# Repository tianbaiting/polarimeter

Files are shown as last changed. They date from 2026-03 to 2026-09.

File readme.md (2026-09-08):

# Deuteron Beam Polarimeter Engineering Repository

The current project baseline contains two compact in-vacuum polarimeters:

1. `CompactInVacuum-afterSRC`, downstream of SRC.
2. `CompactInVacuum-preSAMURAI`, before the SAMURAI terminal.

They share the detector head, three-channel sector-holder architecture, SiPM/scintillator
technology, passive in-vacuum services, calibration approach, and physics studies. Chamber
geometry, beam interfaces, target integration, supports, and maintenance envelopes remain
deployment-specific and must be verified independently.

The external-detector models are preserved under `external_version/` as legacy/reference routes.
Their H+V+V mechanics and historical interface assumptions are not requirements for either
current CompactInVacuum instrument.

## Current architecture

| Workstream | Status | Detector location | Mechanical authority |
|---|---|---|---|
| `compactOneAfterSRC` | current baseline prototype | in vacuum | `docs/specs/compact_one_requirement_baseline.md` |
| `compactOneInfrontSamurai` | current baseline prototype | in vacuum | `docs/specs/compact_one_requirement_baseline.md` |
| `compactInVacuum` | compatibility numerical/CAD scaffold | in vacuum | `docs/specs/compact_one_requirement_baseline.md` |
| `afterSRC` | legacy/reference | outside vacuum | `docs/specs/BLP_v1_requirement_baseline.md` |
| `infrontofSamuraiMag` | legacy/reference | outside vacuum | `docs/specs/BLP_v1_requirement_baseline.md` |

The current afterSRC screening profile uses a provisional 440 x 440 mm square chamber, a
420 mm body, and a top all-metal ICF305 maintenance opening. The removable blank flange owns no
detector support, locating datum, ground termination, or permanent cable restraint. ICF253 is the
rejected access comparison and ICF356 is the enlarged-envelope comparison. The first 12 mm holder
release is validated; the complete reorientation and lift through the port remains unresolved.
Beamline and service-interface values remain evidence-qualified and are not fabrication contracts.

## Repository map

- Start reading the documentation with [中文导航](docs/index_zh.tex) or
  [English guide](docs/index_en.tex). Run `make -C docs` to build the linked reading PDFs.
- `docs/physics/`: polarization production, density matrices and spin transport.
- `docs/analysis/`: counting statistics, coincidence and energy-loss studies.
- `docs/papers/`: research manuscript drafts.
- `compactInVacuum/`: current common platform, both baseline deployment profiles, compatibility
  scaffold, generator, validation, and tests.
- `external_version/afterSRC/`: preserved afterSRC external-detector reference.
- `external_version/infrontofSamuraiMag/`: preserved SAMURAI-front external-detector reference.
- `code/`: ROOT/C++ reconstruction, coincidence, polarization, and plotting tools.
- `docs/specs/compact_one_requirement_baseline.md`: current CompactInVacuum requirement authority.
- `docs/specs/BLP_v1_requirement_baseline.md`: legacy external-route requirement authority.
- `docs/polarimeter_detector/compact_in_vacuum_sipm_report/`: reproducible detector, vacuum,
  energy-loss, and procurement study.
- `docs/beamline_info/`: site-interface evidence and open questions.
- `codex_targets.yaml`: stateful module registry.
- `worklog.md`: cross-module execution and handoff history.

## CompactInVacuum platform

The common hierarchy is:

`active plastic -> optical package -> SiPM -> detector head -> three-channel sector holder -> four-sector internal assembly -> deployment chamber`

The recommended starting head uses a 20 mm diameter, 5.5 mm fast-blue plastic active element and
an NDL EQR15-class SiPM. These values remain prototype recommendations until supplier, optical,
vacuum, and bench-test gates close. Dedicated temperature and housekeeping hardware is not part of
schema 3.

Compatibility labels containing `CompactOne` remain in executable paths; the authoritative
instrument names are `CompactInVacuum-afterSRC` and `CompactInVacuum-preSAMURAI`.

See `compactInVacuum/README.md` for generation details.

## Stateful CAD workflow

The pipeline is:

`target.yaml -> resolved configuration -> generator -> validator -> FCStd/STEP/JSON -> state.json`

Current baseline entries:

```bash
./compactInVacuum/run_compactOne_afterSRC.sh --pipeline-index codex_targets.yaml
./compactInVacuum/run_compactOne_infrontSamurai.sh --pipeline-index codex_targets.yaml
```

Compatibility scaffold:

```bash
./compactInVacuum/run_compactInVacuum.sh --pipeline-index codex_targets.yaml
```

Preserved legacy references:

```bash
./external_version/afterSRC/run_afterSRC.sh --pipeline-index codex_targets.yaml
./external_version/infrontofSamuraiMag/run_infrontofSamuraiMag.sh --pipeline-index codex_targets.yaml
```

Targets and configuration are human-owned. Runtime state, locks, generated CAD, and validation
reports are machine-written. Interpret a result using both validation status and validation mode:
a non-strict pass is a prototype geometry pass, not a fabrication/release pass. Fabrication claims
require `strict=true`, `status=pass`, and closure of the applicable supplier, interface, access,
vacuum, site-envelope, and structural evidence gates.

## Cross-machine reproducibility

Compare Git commit, resolved configuration, FreeCAD/Python versions, validation mode/results,
solid counts and bounding boxes, volumes and screening masses, detector coordinates and physics
metrics, target states, service routing, and access checks. Byte-identical FCStd or STEP output is
not required.

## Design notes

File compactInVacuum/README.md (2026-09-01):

# CompactInVacuum Common Platform

The baseline comprises:

- `CompactInVacuum-afterSRC`
- `CompactInVacuum-preSAMURAI`

The `compactInVacuum/` and `CompactOne` names remain executable compatibility labels. External detector routes remain preserved legacy/reference implementations and are not modified by the common-platform redesign.

## Preferred hierarchy

`detector head -> three-channel sector holder -> four-sector internal assembly -> deployment chamber`

The old 35 mm nose, 44 mm cassette box, long cassette thermal bridge, independent wall rails, wall anchors, and temperature/housekeeping system are superseded.

## Detector head

The default prototype contains:

- 20.0 × 5.5 mm fast plastic active element;
- 0.25 mm reflector envelope;
- 0.50 mm optical coupling;
- 1.50 mm NDL EQR15-class SiPM package;
- 1.20 mm provisional sensor PCB/carrier;
- 1.00 mm rear mounting face;
- shallow light-tight sleeve;
- 3.0 mm short cable exit;
- separate 20.0 mm connector keepout.

Calculated physical housing depth:

`5.50 + 0.50 + 1.50 + 1.20 + 0.00 + 1.00 = 9.70 mm`

Cable and connector keepouts do not increase this metric. The default gate is 18.0 mm.

## Sector holder

One coherent carrier holds deuteron, small-angle proton, and large-angle proton heads. Each nest has an insertion stop, D-flat anti-rotation land, removable clamp bridge, and two provisional M3 fastener envelopes. One common plate provides acceptance relief, a rear cable lane, survey datums, and a plane–pin–slot chamber interface.

Heads remove rearward after clamp release. For the current afterSRC fixed-wall study, exact solid
poses validate only the first 12 mm inward release from the stationary support. The subsequent
translation, reorientation, and lift through the top ICF305 opening remain unresolved; the former
70 mm straight radial motion is not evidence of complete extraction.

The removable access closure owns no detector support, locating datum, protective-ground
termination, or permanent cable restraint. All holder load paths remain on stationary supports
that contact permanent chamber walls.

## Monitoring disposition

Dedicated temperature monitoring is removed. There is no physical sensor, temperature harness, required temperature channel, housekeeping capacity rule, or housekeeping feedthrough. Schema version 3 rejects the removed fields.

## Display roles

Physical and purchased-component/interface objects are visible by default. Keepouts, datums, service centerlines, physics acceptance, and optional reference objects are hidden. Active plastic, coupling, SiPM, carrier, housing, and holder have distinct inspection colors when GUI state is available.

## Configuration

- Common schema-v3 platform: `config/common_detector.yaml`
- afterSRC deployment: `config/afterSRC_compact.yaml`
- pre-SAMURAI deployment: `config/infrontSamurai_compact.yaml`
- legacy entry-point compatibility: `config/default_compactInVacuum.yaml`

See `MIGRATION.md` for rejected fields and mappings.

## Generation and validation

```bash
./compactInVacuum/run_freecad_tests.sh

./compactInVacuum/run_compactOne_prototypes.sh \
  ./compactInVacuum/config/afterSRC_compact.yaml \
  ./compactInVacuum/artifacts/prototypes

./compactInVacuum/run_compactOne_afterSRC.sh \
  --pipeline-index codex_targets.yaml \
  --force-rebuild

./compactInVacuum/run_compactOne_infrontSamurai.sh \
  --pipeline-index codex_targets.yaml \
  --force-rebuild
```

Non-strict validation permits documented evidence warnings but never geometry, collision, capacity,
or acceptance failures. A non-strict pass is a prototype geometry result, not a fabrication release.
Strict mode additionally requires supplier drawings, site envelopes, vacuum-material evidence,
chamber-access closure, and pressure-vessel analysis. It does not require removed monitoring hardware.

Generated CAD, screenshots, caches, and runtime state remain untracked unless intentionally selected as reference artifacts.

## Physics disposition

The redesign preserves 53.4° for the large-angle proton and 11.2° for the small-angle proton. Previously supplied nominal values of approximately 55.9° and 11.3° remain unresolved pending evidence.

## Authorities

- `docs/specs/compact_one_requirement_baseline.md`

Supporting records:

- `docs/specs/compact_one_architecture_audit.md`: dated implementation snapshot; later baseline
  revisions supersede conflicting extraction or access claims.
- `compactInVacuum/MIGRATION.md`: schema migration guide, not a mechanical requirement authority.

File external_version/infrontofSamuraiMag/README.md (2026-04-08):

# infrontofSamuraiMag User Guide

This module builds, validates, and exports the BLP v1 in-front polarimeter concept assembly.

## 0. Worklog Protocol (Mandatory)

Before edits/runs, read:
- `worklog.md`
- `infrontofSamuraiMag/worklog.md`

After every stateful run (including `--validate-only`), append one English entry to both files with:
- timestamp (UTC + local),
- command and key overrides,
- validation/state result,
- next action.

## 1. Run Commands

Stateful pipeline entry (required for module work):

```bash
./infrontofSamuraiMag/run_infrontofSamuraiMag.sh --pipeline-index codex_targets.yaml
```

Legacy ad-hoc entry scripts have been removed. Use the stateful shell entry above instead of direct one-off Python or FreeCAD macro wrappers.

Force rebuild (bypass hash-skip):

```bash
./infrontofSamuraiMag/run_infrontofSamuraiMag.sh --pipeline-index codex_targets.yaml --force-rebuild
```

Validate only (strict gate):

```bash
./infrontofSamuraiMag/run_infrontofSamuraiMag.sh --pipeline-index codex_targets.yaml --validate-only --strict-validation
```

V2 full-path LOS trial (legacy mode with overrides):

```bash
./infrontofSamuraiMag/run_infrontofSamuraiMag.sh --pipeline-index codex_targets.yaml --validate-only --strict-validation \
  --set geometry.clearance.los_scope=v2_fullpath \
  --set geometry.chamber.los_channels.enabled=true \
  --set geometry.chamber.los_channels.channel_diameter_mm=96.0 \
  --set geometry.chamber.los_channels.channel_start_z_mm=8.0 \
  --set geometry.chamber.los_channels.channel_length_mm=1600.0 \
  --report-json /tmp/infront_v2_los_report.json
```

## 2. CLI Options

- `--config <path>`: config file path.
- `--set <key=value>`: dotted override (repeatable).
- `--output-dir <path>`: override `output.dir`.
- `--basename <name>`: override `output.basename`.
- `--formats <csv>`: override output formats (`fcstd,step`).
- `--dump-resolved-config`: print normalized config snapshot.
- `--doc-name <name>`: FreeCAD document name.
- `--validate-only`: run validation without CAD export.
- `--strict-validation` / `--no-strict-validation`: exit non-zero on validation fail.
- `--report-json <path>`: explicit report path.
- `--angle-tol-deg <v>`: angle tolerance.
- `--radius-tol-mm <v>`: radius tolerance.
- `--pipeline-index <path>`: resolve target/state from root index.
- `--force-rebuild`: force run even if target hash unchanged.

## 3. Development Environment (Reproducible)

Create a dedicated virtual environment for tests and config checks:

```bash
python3 -m venv infrontofSamuraiMag/.venv-pytest
infrontofSamuraiMag/.venv-pytest/bin/pip install -r infrontofSamuraiMag/requirements-dev.txt
```

Run test gate:

```bash
infrontofSamuraiMag/.venv-pytest/bin/python -m pytest -q infrontofSamuraiMag/tests
```

Layered test gate with dependency precheck:

```bash
infrontofSamuraiMag/.venv-pytest/bin/python infrontofSamuraiMag/scripts/precheck_test_env.py --layer pure_python
infrontofSamuraiMag/.venv-pytest/bin/python infrontofSamuraiMag/scripts/precheck_test_env.py --layer freecad_runtime
PYTHON_BIN=infrontofSamuraiMag/.venv-pytest/bin/python ./infrontofSamuraiMag/run_tests_layered.sh pure_python
PYTHON_BIN=infrontofSamuraiMag/.venv-pytest/bin/python ./infrontofSamuraiMag/run_tests_layered.sh freecad_runtime
```

## 4. Config Structure (`config/default_infront.yaml`)

### 4.1 geometry.beamline
- `axis`
- `inlet_diameter_mm`

### 4.2 geometry.chamber
- `core.size_x_mm / size_y_mm / size_z_mm / wall_thickness_mm`
- `end_modules.front_standard / rear_standard`
- `end_modules.module_outer_diameter_mm / module_inner_diameter_mm / module_thickness_mm`
- `end_modules.seal_face_width_mm / bolt_circle_diameter_mm / bolt_count`
- `end_modules.oring_groove_width_mm / oring_groove_depth_mm`
- `end_modules.interface_bolt_* / interface_nut_* / interface_washer_*` (replaceable interface fastening hardware)
- `los_channels.enabled / channel_diameter_mm / channel_start_z_mm / channel_length_mm` (used by LOS v2 full-path channel cuts)

### 4.3 geometry.ports
- `main_pump / gauge_safety / rotary_feedthrough / spare`
- each port: `side / center_z_mm / inner_diameter_mm / outer_diameter_mm / length_mm`

### 4.4 geometry.plate.h / v1 / v2
- `orientation` (`horizontal` or `vertical`)
- `mount_plane` (`xy` for H, `yz` for V1/V2; parser also accepts `xz` for non-default layouts)
- `offset_mode` (`manual` or `auto`; auto resolves plate-normal offset to minimum outside-chamber position + `plate_auto_gap_mm`)
- pose: `z_mm / offset_x_mm / offset_y_mm`
- panel: `width_mm / height_mm / thickness_mm`
- LOS opening: `inner_radius_mm / outer_radius_mm / sector_opening_deg / azimuth_centers_deg[]`
- load-bearing: `lug_* / bolt_hole_* / stiffener_*`

### 4.5 geometry.detector
- `clamp`: detector body/clamp/support parameters
  - includes `support_mount_block_*` and `support_mount_hole_diameter_mm`
  - includes `clamp_ear_* / clamp_bolt_* / anti_rotation_key_*` for split-clamp fastening and anti-rotation key features
- `adapter_block`: fixed-angle transition block parameters

### 4.6 geometry.target
- `ladder`: 3-position ladder + drive semantics
  - includes `motor_mount_* / hard_stop_* / index_*`
- `holder`: removable holder and target thicknesses
  - includes `clamp_screw_*` for dual-screw clamp realization

### 4.7 geometry.stand
- base/support/anchor/leveling/shim parameters
- includes `plate_tie_*` for plate-to-stand load-transfer columns/caps/bolts

### 4.8 geometry.clearance
- `los_scope` (`v1_conceptual` or `v2_fullpath`)
- `los_margin_mm`
- `vv_min_gap_factor` (V1/V2 clear-gap multiplier against detector clamp outer diameter; default `2.0`)
- `plate_auto_gap_mm` (minimum plate-normal gap used by auto offset solver)
- `plate_chamber_cutout_margin_mm` (plate-vs-chamber cutout margin; default `5.0`)
- `los_detector_active_face_offset_mm`
- `detector_front_to_chamber_mm`
- `detector_pair_min_gap_mm`
- service clearances

### 4.9 layout
- `sectors: [left, right, up, down]`
- `channels[]`: `name / angle_deg / radius_mm / confidence`

### 4.10 output
- `dir / basename / formats`

## 5. Validation Report

JSON report is grouped by subsystem:
- `chamber`
- `plates`
- `detector`
- `target`
- `stand`

Global pass condition requires all subsystem checks to pass.

## 6. Artifacts

Expected outputs:
- `*.FCStd`
- `*.step`
- `*.validation_report.json`
- `state.json` (stateful run record)

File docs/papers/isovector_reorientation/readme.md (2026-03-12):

Section IV.  {Simulation of the detection at SAMURAI}

{ -subsection A: {detector setup}

  -subsection B: {target position optimization}
  
  -subsection C: {response of neutron with nebula}
  
  -subsection D: {response of proton with PDC}
  
  -subsection E: {Beam dumper and the background simulation}
  
  -subsection F: {Observation of the IVR effect in the current experimental design}
  
} 

We intend to optimize the reaction vertex in the SAMURAI dipole to make the best use of the coverage of the detectors. \textcolor{blue}{Here, $b$ is the impact parameter, defined as the perpendicular distance between the centers of the deuteron and target nucleus at closest approach, and $\rho$ is the nuclear matter density.} According to the Improved Quantum Molecular Dynamics (ImQMD) model calculations, for the scattering events with $b = 7 \sim 9$~fm, which is the range showing the most sensitivity of the IVR effect to the $\gamma$ parameter \textcolor{blue}{(where $\gamma$ characterizes the density dependence of the symmetry energy $E_{\rm sym}(\rho)$)}, the most probable direction of the breakup neutrons is not very close to $\theta = 0^\circ$. \textcolor{blue}{The SAMURAI spectrometer is a large-acceptance superconducting dipole magnet, providing high-resolution momentum analysis and wide angular coverage for charged particles.} Considering that NEBULA is difficult to move, in order to measure the neutrons in the most favorable range of $\theta_{\mathrm{n}}$, it is suggested to place the target upstream of the magnet, at a distance of 3 meters from the center of the magnet, which ensures that the range of $-10^\circ \leq \theta_{\mathrm{n}} \leq 10^\circ$ is covered for the most probable neutron emissions.

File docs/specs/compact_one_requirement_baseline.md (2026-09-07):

# CompactInVacuum Requirement Baseline v2.8

## 1. Authority and scope

This document is the requirement authority for the common CompactInVacuum detector platform and its two baseline deployments:

1. `CompactInVacuum-afterSRC`, downstream of SRC.
2. `CompactInVacuum-preSAMURAI`, upstream of the SAMURAI terminal.

Both deployments place the compact plastic-scintillator detector heads, SiPM packages, passive internal services, and sector holders inside vacuum. Detector technology and common mechanical architecture are shared. Chamber geometry, purchased beamline interfaces, target integration, external supports, and installation envelopes remain deployment-specific.

The external-detector implementations in `external_version/afterSRC/` and
`external_version/infrontofSamuraiMag/` are legacy/reference routes. They shall remain independently
testable and shall not be modified, deleted, or silently promoted into this baseline.

Compatibility labels containing `CompactOne` and the directory `compactInVacuum/` may remain in executable paths. The instrument names above are authoritative.

## 2. Decision and evidence states

Engineering selections use:

- `FROZEN`: approved project requirement.
- `PROVISIONAL`: current integration value requiring evidence.
- `RECOMMENDED`: preferred prototype candidate; alternatives remain open.
- `PLACEHOLDER`: architecture-only value that fails an applicable strict gate.
- `PURCHASED-PART-CONTRACT`: governed by a supplier or certified drawing.

Unknown quantities remain `TBD` or unresolved. Exact-looking dimensions shall not be invented.

Deployment interface claims use:

- `A — EXTERNAL CONSTRAINT`
- `B — LEGACY INHERITANCE`
- `C — ENGINEERING ASSUMPTION`
- `D — UNRESOLVED / TBD`

## 3. Frozen common-platform requirements

- Four sectors: LEFT, RIGHT, UP, DOWN.
- Three channels per sector: deuteron, small-angle proton, large-angle proton.
- Twelve active detectors total.
- Detector axes point toward the target center.
- Configured radii refer to active-plastic centers.
- One nominal 50-ohm signal path per detector; bias may share the coax through external bias tees.
- Active amplifiers, bias tees, and digitizers remain outside vacuum by default.
- One removable three-detector holder per sector.
- Full target-region-to-complete-active-disc acceptance is preserved.
- Coincidence geometry and per-channel active-acceptance metrics are exported.
- Physical CAD is separated from keepouts, datums, service centerlines, and physics overlays.
- Both baseline deployments generate independently.
- Preserved external routes remain unchanged and independently regressible.

## 4. Temperature-monitoring disposition

A dedicated temperature-monitoring or thermometer-style subsystem is not a platform requirement.

The common platform shall not contain or require:

- a physical `TemperatureSensor`;
- per-detector temperature channels;
- temperature harnesses or centerlines;
- wires-per-temperature-channel capacity;
- a housekeeping feedthrough;
- a housekeeping capacity gate;
- a resolved temperature-sensor supplier model;
- temperature manifests or generated metrics.

These elements shall be removed rather than hidden. Schema version 3 rejects their former configuration keys with a migration error.

An optional deployment-level spare auxiliary interface may be introduced in a future revision only if justified. It shall default to disabled, create no physical feedthrough or cable when disabled, use neither “temperature” nor “housekeeping” terminology, and remain outside required validation.

## 5. Detector-head prototype

The semantic axial stack is:

1. fast plastic scintillator;
2. thin reflector/light-treatment envelope;
3. optical coupling layer;
4. SiPM package;
5. minimal sensor PCB or metallic carrier;
6. shallow light-tight rear mounting face;
7. short cable exit.

The recommended starting prototype is:

| Component | Default value | Status |
|---|---:|---|
| active plastic diameter | 20.0 mm | recommended |
| active plastic thickness | 5.5 mm | recommended within 5–6 mm |
| reflector radial envelope | 0.25 mm | placeholder material |
| optical coupling thickness | 0.50 mm | provisional |
| SiPM package depth | 1.50 mm | recommended candidate envelope |
| sensor PCB/carrier depth | 1.20 mm | provisional |
| rear internal clearance | 0.00 mm | provisional |
| rear mounting-face thickness | 1.00 mm | provisional |
| SiPM candidate | NDL EQR15 11-6060D-S | recommended |
| SiPM active class | approximately 6 × 6 mm | recommended |

The default physical housing depth is calculated, not independently specified:

`5.50 + 0.50 + 1.50 + 1.20 + 0.00 + 1.00 = 9.70 mm`

The physical-depth gate is 18.0 mm maximum from active entrance face to rear physical housing. The 3.0 mm short cable exit and the 20.0 mm connector keepout are reported separately and do not increase this metric.

The reflector envelope surrounds the active plastic without covering its complete entrance face. The coupling contacts the active rear readout region. The SiPM is centered directly behind the coupling. The carrier contacts the SiPM and rear mounting face, providing a real passive conductive path without an artificial long thermal bridge.

The light-tight housing is a shallow sleeve and rear face. It shall not recreate the former 35 mm nose plus 44 mm rectangular package. Semiconductor microstructure and detailed connector internals are out of scope.

The rear mounting face provides the insertion stop and mounting datum. A D-flat and matching nest land provide anti-rotation without protruding into a neighboring acceptance cone. Detector removal is axial and rearward after clamp release. The default sampled withdrawal distance is 12.0 mm, sufficient to clear the 3.0 mm nest.

The carrier, cable exit, connector, reflector selection, and detailed PCB remain provisional until drawings or prototype measurements resolve them.

## 6. Sector holder

Each sector uses one coherent fabricated or machined carrier containing exactly:

- one deuteron detector head;
- one small-angle proton detector head;
- one large-angle proton detector head.

The active deployments use four detailed boxed carriers with two relieved cheeks, front/rear crossmembers, three rear nests and removable clamps, three routed passive coax connections, and one radial plane–pin–slot dock per sector. A common annular support near z=140 mm transfers load to the permanent side and bottom walls. The former rear C-frame is retained only as a comparison configuration.

A removable downstream retaining bridge clamps each dock with two axial screw envelopes. The bridge, screws, locating pins and coax/ground interfaces are represented for every sector. A rear-facing cylindrical handling journal projects behind each carrier; its capture tool remains vertical in the chamber coordinate system.

The specified service sequence is UP, RIGHT, LEFT, DOWN; installation reverses this sequence. It supersedes the former independent-removal design target for this prototype. Each module disengages radially inward, translates downstream, turns about its handling journal if needed, centers under the ICF305 port, and lifts upward. Other sectors remain physical obstacles until their preceding removal step is complete. Validation must distinguish loaded-module/capture-tool transport from connection release, retaining-bridge access, and purchased capture mechanism qualification. A clear transport path alone shall not be called a complete maintenance-process certificate.

The cheeks, crossmembers, nests, clamps, and fastener envelopes shall clear every complete active-acceptance cone. The crossmembers include the declared cable and handling-journal reliefs. Arbitrary per-detector wall rails, wall anchors, cylindrical thermal straps, and a synthesized wall backbone are prohibited.

The holder is a provisional manufacturable concept, not a released drawing. Tool access, chamber closure, pin retention, tolerances, surface finish, and production fasteners remain to be resolved.

Every removable sector-holder structural interface shall contact either a permanent chamber wall or a separately defined stationary load-bearing pad/pedestal with zero geometric gap. Every stationary pad/pedestal shall in turn contact a permanent chamber wall, or the explicitly defined common stationary support frame, with zero gap. The common frame shall contact permanent side/bottom walls with zero gap. A protective-ground strap is electrical bonding only and shall never be used to bridge a structural mounting gap or satisfy the load path.

## 7. Physical and overlay roles

Every generated object has one engineering role:

- `physical`
- `purchased_component_interface`
- `keepout`
- `datum`
- `service_centerline`
- `physics_acceptance`
- `optional_reference_geometry`

Default visibility is:

| Role | Default |
|---|---|
| physical | visible |
| purchased component/interface | visible |
| keepout | hidden |
| datum | hidden |
| service centerline | hidden |
| physics acceptance | hidden |
| optional reference geometry | hidden |

Generated documents use meaningful groups including `DetectorHead`, `SectorHolder`, `Target`, `Services`, `Chamber`, `Keepouts`, `Datums`, `PhysicsAcceptance`, and `OptionalReference` where applicable.

Material-based colors and transparency support inspection but are not geometry requirements. The active plastic, optical coupling, SiPM, PCB/carrier, housing, and holder shall remain visually distinguishable.

## 8. Services and passive thermal path

- Twelve signal channels are required.
- Four sector-grouped signal feedthrough interfaces provide sixteen provisional slots.
- One protective/equipotential bond per sector is required.
- Signal shields are not the sole protective-earth path.
- Each protective bond shall have nonzero physical length and contact both the removable holder/block and the stationary support/permanent chamber. A zero-length marker, virtual datum, locating pin, or coax shield does not satisfy this requirement.
- Cable routes, connector keepouts, bend envelopes, and centerlines are nonphysical overlays unless explicitly classified otherwise.
- No dedicated temperature or housekeeping feedthrough is generated.

The conductive path contract is:

`SiPM package -> sensor PCB/carrier -> rear mounting face -> detector nest -> sector carrier plate -> chamber mounting interface`

The path represents contact connectivity. It is not thermal FEA and shall not be satisfied by adding a fictitious long bridge.

## 9. Physics geometry

The repository values remain:

| Channel | Repository value | Previously supplied nominal | Disposition |
|---|---:|---:|---|
| proton large | 53.4° | approximately 55.9° | unresolved; do not change without evidence |
| proton small | 11.2° | approximately 11.3° | unresolved; do not change without evidence |

This mechanical redesign does not resolve the discrepancy. Active-center radii and directions remain unchanged.

Validation exports active-center angle/radius, active-face radius, angular extent, approximate solid angle, and eight configured coincidence pair metrics. It does not claim detector-response or Geant4 fidelity.

## 10. Acceptance and collision validation

The complete ruled volume from the active target region to each complete active disc is checked against:

- target hardware;
- every other detector head;
- carrier plates, nests, clamps, and interface blocks;
- simplified purchased fastener envelopes;
- cable and connector keepouts;
- service hardware;
- chamber hardware.

Validation also requires:

- twelve non-null, valid detector-head solids;
- no detector-head overlap;
- four non-overlapping three-head sector assemblies;
- clear detector withdrawal after clamp release;
- clear sampled configured holder-release poses, without treating them as proof of complete extraction;
- clear target motion sweep;
- clear signal routing;
- a closed vacuum control volume;
- all internal physical parts inside the selected chamber;
- connected passive thermal paths.
- zero-gap removable-holder-to-stationary-support and stationary-support-to-permanent-wall structural paths;
- no detector support, locating pin, ground bond, or permanent support inside the removable access-closure lift corridor.

## 11. Deployment profiles

### 11.1 CompactInVacuum-afterSRC

- Baseline instrument downstream of SRC.
- Selected screening chamber: square 440 × 440 mm internal section, provisional. The active ICF305 maintenance-access integration study length is 420 mm with the upstream outer face retained at `z=-50 mm`; the former 360 mm body remains the ICF253 comparison envelope and is not silently treated as the active access-port design.
- A cylindrical afterSRC chamber is not part of the selected CompactInVacuum-afterSRC profile.
- Front/rear ICF114 values are legacy/provisional evidence, not approved site requirements.
- The maintenance opening is a top-wall circular ICF port with a removable ICF blank flange. Elastomer/O-ring sealing is prohibited for this deployment; the screening seal is an oxygen-free-copper metal gasket. The maximum allowable helium leak rate is `1.0e-10 Pa m^3/s`, based on the user-supplied Toshiba inspection sheet; document identity and applicability to the complete compact chamber remain to be closed before fabrication release.
- The access-port comparison family is `ICF253`, `ICF305`, and `ICF356`. Vendor-catalog screening dimensions distinguish the flange hole from the applicable pipe outside diameter: ICF253 uses a `198.5 mm` flange bore / `203 mm` pipe OD, ICF305 uses `251.0 mm` / `254 mm`, and ICF356 uses `301.8 mm` / `305 mm`. ICF305 is the active recommended prototype; ICF253 remains a smaller-port comparison requiring reorientation; its former side-wall UP-holder rejection is historical and shall not be applied unchanged to the new common-frame carrier, and ICF356 remains the enlarged-envelope comparison.
- A top access flange alone does not close the sector-removal requirement. Validation shall separately report: flange-to-chamber fit, flange-to-service-port clearance, detached-holder passage screening, and the complete installed-holder release/reorientation/lift path. The existing straight `70 mm` radial release path shall not be re-labelled as a successful top-port extraction path.
- The removable ICF fixed/blank closure owns no detector support, locating datum, structural fastener, thermal sink, protective-ground termination, cable clamp, or target-mechanism load. Removing the blank flange shall leave all internal detector supports positioned on permanent chamber structure.
- Both compact deployments use the boxed carriers and annular support defined above, four radial sector docks, and deployment-specific permanent-wall feet. This supersedes the former afterSRC UP `-X` pedestal at `y=180 mm`.
- Available envelope, the complete service-removal motion, purchased ICF305 interface drawing, support datum, and pressure-vessel release remain unresolved.
- The preserved external afterSRC route remains a legacy fallback/reference.

### 11.2 CompactInVacuum-preSAMURAI

- Baseline instrument upstream of the SAMURAI terminal.
- Selected screening chamber: square 450 × 450 mm internal section, provisional; the ICF305 top-access prototype uses a 420 mm body with upstream outer face at `z=-50 mm`. The former 380 mm service-plate chamber remains a comparison candidate.
- The top maintenance opening adopts the same provisional ICF305 geometry and load-free closure as afterSRC; supplier, seal/site applicability, and complete extraction evidence remain unresolved. Signal services occupy the permanent upstream top strip outside the maintenance flange.
- VF100/VG80 evidence inherited from external work is not automatically authoritative for the compact deployment.
- Available envelope, mating-chain ownership, service-removal closure, purchased interface drawings, support datum, and pressure-vessel release remain unresolved.
- The preserved external SAMURAI-front route remains reference engineering work.

## 12. Strict-validation semantics

Non-strict mode permits explicit warnings for unresolved supplier, material, site-envelope, chamber-access, and pressure-vessel evidence. Geometry, capacity, acceptance, collision, and schema failures remain fatal.

Strict mode converts applicable evidence warnings to failures. Strict validation shall not fail because a removed temperature sensor, temperature harness, housekeeping channel, or housekeeping feedthrough is absent.

Current legitimate strict gates include:

- reflector/optical and SiPM supplier evidence;
- carrier/PCB definition;
- purchased beam and signal-interface drawings;
- vacuum material and cleaning evidence;
- chamber external-pressure/buckling FEA;
- site envelopes;
- resolved sector-removal access closure.
- afterSRC maintenance-port metal-seal evidence, helium-leak acceptance, flange/service clearances, and complete extraction motion.

## 13. Schema migration

CompactInVacuum schema version 3 replaces:

- `detector.cassette` with `detector.head`;
- `sector_cartridge` with `sector_holder`;
- arbitrary outer detector length with calculated stack depth;
- protruding `anti_rotation_tab_mm` with `anti_rotation_flat_depth_mm`.

Schema version 3 rejects all former temperature and housekeeping fields. They are not ignored and no compatibility geometry is created. Deployment service-port roles are limited to `rotary` and `signal`.

Legacy schema-1 compatibility profiles remain loadable for the preserved old entry point, but their dedicated housekeeping block has also been removed.

## 14. Required artifacts

The redesign shall generate:

- isolated detector head: FCStd, STEP, geometry metrics JSON, PNG;
- transparent/exploded detector head: FCStd, STEP, geometry metrics JSON, PNG;
- three-channel sector holder: FCStd, STEP, geometry metrics JSON, PNG;
- four-sector internal assembly: FCStd, STEP, geometry metrics JSON, validation JSON, PNG;
- CompactInVacuum-afterSRC: FCStd, STEP, geometry metrics JSON, validation JSON, PNG;
- CompactInVacuum-preSAMURAI: FCStd, STEP, geometry metrics JSON, validation JSON, PNG;
- before/after comparisons for detector side, sector, and internal assembly;
- separate diagnostic renders with keepouts and acceptance volumes visible.

Runtime state, caches, and machine-specific files remain untracked.

## 15. Evidence still required

- Approved afterSRC and pre-SAMURAI site envelopes and interface drawings.
- Certified purchased beam-interface and signal-feedthrough drawings.
- Resolved PCB/carrier, connector, cable, strain-relief, reflector, and optical-pad choices.
- Prototype optical collection, timing, uniformity, saturation, and vacuum/bake testing.
- Sector-holder tolerances, tool access, pin retention, fasteners, finish, and fabrication drawings.
- Chamber access closure and sector extraction demonstration.
- Vacuum material/cleaning qualification.
- Chamber external-pressure, weld, support, transport, and seismic/load analysis as applicable.
- Evidence resolving 53.4° versus approximately 55.9°, and 11.2° versus approximately 11.3°.

## 16. Change history

- 2026-09-07 v2.8: user selected top rotary, left-wall signal feedthroughs and right-wall maintenance access; replace the inaccessible annular weldment with individually installable local supports and include initial support installation in validation.

- 2026-09-07 v2.7: promoted four detailed boxed modules to both canonical deployments, with a permanent annulus, downstream retaining bridges, rear handling journals, complete installed/parked signal looms and the UP/RIGHT/LEFT/DOWN service sequence. Loaded-module and modeled capture/bridge motion remain distinct from full service-tool and fabrication qualification.

- 2026-09-06 v2.6: authorized one detailed RIGHT-sector boxed-carrier study on a near-detector annular support, with connector disconnection, tool access and complete controlled extraction. This is an isolated design study, not replacement of either canonical deployment.
- 2026-09-06 v2.5: selected the common rear open C-frame, four axial-release sector docks, and top ICF305 access for both compact prototypes; retained independent complete extraction as an unresolved design target.

- 2026-09-01 v2.4: clarified that sampled holder-release poses do not constitute proof of the
  complete extraction path; aligned downstream documentation and validation terminology with the
  ICF305 fixed-wall support design.
- 2026-07-27 v1.0: established a common CompactInVacuum platform with two baseline deployments.
- 2026-07-29 v2.0: removed temperature monitoring end-to-end; replaced the long cassette with a 9.70 mm calculated detector head; replaced arbitrary rails with one coherent sector carrier; added engineering display roles, removal validation, and schema-v3 migration.
- 2026-07-29 v2.1: selected the square 440 × 440 mm screening chamber for CompactInVacuum-afterSRC and removed its cylindrical chamber candidate.
- 2026-08-30 v2.2: froze the afterSRC maintenance opening as an all-metal top ICF port with an oxygen-free-copper gasket and `1.0e-10 Pa m^3/s` helium-leak criterion; added ICF253/305/356 comparison candidates, selected ICF305 for the active prototype, and kept complete sector extraction as an independently validated unresolved motion.
- 2026-08-30 v2.3: prohibited all detector support/datum/ground ownership on the removable ICF closure; required zero-gap removable-holder-to-stationary-pad-to-permanent-wall load paths; and moved the afterSRC UP-sector mount from the opened `+Y` wall to a stationary `-X` side-wall pedestal while keeping the long wall-reaching member out of the removable holder.

## 17. Boxed-sector design study

The registered `compactBoxedSectorStudy` first develops one complete RIGHT sector using the unchanged three active detector positions and the afterSRC ICF305 chamber. Its candidate carrier uses two side cheeks, three nests, local crossmembers, a plane-pin-slot docking foot and an accessible draw screw. A fixed annular support near the large-angle detector transfers load to permanent side/bottom walls. The ring is retained during routine detector maintenance; segmentation and fabrication release are separate decisions.

The study must include real detector-head solids, retention and docking interfaces, three passive pigtails and their disconnect envelopes, protective bonding, a defined grasping joint and the handling-tool envelope. The other three sectors are reserved by conservative module envelopes, supplemented by their actual detector-head solids. Results shall explicitly identify this single-sector scope.

Maintenance is performed with the blank flange and gasket removed. Connector plugs are withdrawn and parked before the module moves. A capture tool supports the module before its draw screw is removed. The module releases inward, translates downstream, turns on a controlled joint whose axis is parallel to beam Z, centers below the opening and lifts out. The handling rod stays vertical. This refines the conceptual beam-axis turn into an executable tool-controlled motion.

Check the complete modeled motion against permanent support, chamber, flange, services and the three reserved sectors. Discrete clear poses alone do not prove motion clearance: use analytic swept envelopes or interval certificates based on minimum shape distance and an upper bound on point displacement. Any collision or interval left uncertified shall fail the motion gate. Intended mating contacts require explicit geometric certificates; they cannot be bypassed by blanket obstacle exclusions. The full aperture is retained; do not shrink an arbitrary keepout to make a mechanism pass.

Transport dimensions, microcoax bend radius, connector/capture-tool envelopes and fabrication details are provisional. Geometry certification applies only to those modeled envelopes. Supplier/material qualification, stiffness, clamp preload, human reach/handling forces and available external headroom remain strict evidence gates. No manufacturing release or four-sector detailed-assembly claim follows from this study.

## 18. Complete boxed deployment integration

Both canonical deployments shall export all four detailed carriers, twelve complete detector heads, four locating-pin pairs and retaining bridges, twelve installed signal looms, four ground bonds, the common permanent annular support, the selected chamber, target and deployment-specific beamline interfaces. Neighbor reservation boxes are not a substitute for any of the four physical modules.

The common dimensional source is `compactInVacuum/config/common_boxed.yaml`. Sector placement, removal order, rear handling journal, axial retaining bridges and service-parking coordinates are provisional integration parameters there. The upper-sector parking fixture attaches to the permanent left wall, clear of the top opening. The rear journal and tool provide a path behind the three loaded detector heads, especially for the final DOWN removal. A separate maintenance-open document and extraction poses supplement each closed canonical assembly. The original single-RIGHT-sector study remains a reproducible comparison and does not certify the complete deployments.

All strict evidence gates in section 12 apply to the new canonical engine, including beam/signal/access supplier drawings, materials and optical components, chamber pressure integrity, site/overhead envelope, fastener and capture-mechanism detail, and physical service handling. Geometry failures remain fatal; unresolved evidence remains explicitly non-strict prototype-only.

The full-deployment inward staging travel is 40 mm before the 96 mm downstream transfer. This reduces the rear handling-rod offset to 30 mm, keeping the complete vertical rod inside the circular opening during transfer. It replaces the single-sector study's 14 mm initial release for the full deployment; detector operating positions remain unchanged.

Each retaining bridge first disengages downstream by 20 mm, steps radially outward by 20 mm to clear the rear crossmember, steps 26 mm tangentially away from the engaged handling rod, transfers another 40 mm downstream, centers below the opening and lifts out. The loose bridge and fastener solids are included in the trajectory checks; the actuating/holding tool remains a purchased-mechanism qualification item.

## 19. Side-access baseline superseding the annular support

The two active deployments retain the rotary target axis and its feedthrough on the positive-Y top wall. The four signal feedthroughs move to the negative-X side wall. The metal-sealed ICF305 maintenance opening moves to the positive-X side wall; its center starts at y=0, z=190 mm. Beam interfaces remain on the upstream/downstream Z end walls and retain their deployment-specific contracts. All twelve active detector coordinates remain frozen. Sections 6, 11 and 18 describe the preceding annular prototype wherever inconsistent with this section; it is preserved as a reference only.

There shall be no annular support in the new physical assembly. UP, DOWN and LEFT use short local wall supports. RIGHT uses a local cantilever rooted on permanent wall upstream of the maintenance opening. Small factory-welded wall pads, blind mounting bores, removable support bodies, mounting fastener envelopes and locating pins are modeled. The removable closure and its flange shall carry no detector support or permanent cable load. Every removable support body shall have a checked insertion path through the side opening into the otherwise empty chamber; endpoint fit or contact area alone is insufficient. Factory welding, final machining, chamber deformation and bolt preload remain fabrication evidence gates.

The provisional removal sequence is RIGHT, DOWN, UP, LEFT, reversed for installation. Inward staging starts at 42 mm, downstream transfer at 96 mm, and extraction is toward +X. Capture geometry retains gravity-supporting journal contact while the operating rod approaches horizontally. Capture approach, module motion, retaining-bridge motion and initial support installation shall be reported separately from unqualified flexible service handling and purchased tool internals. The conservative contact and continuous-motion requirements in section 17 remain applicable.

Side-port configuration lives in the two selected deployment YAML files; common support and handling parameters live in `config/common_side_access.yaml`. Both canonical closed/open FCStd assemblies, four real loaded sectors and each sector's side-extraction keyposes are required. A successful ring-era report shall not be reused as side-access evidence.

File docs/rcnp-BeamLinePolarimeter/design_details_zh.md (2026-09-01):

# RCNP BLP 设计细节查询

> 状态：2026-09-01 重新分类为外置探测器/RCNP 类比参考。本文中的 50 mm 外置探测器、
> 0.40/0.62 m 半径、窗口薄膜和多靶位线性靶梯不是当前 CompactInVacuum 基线约束。
> 当前需求以 `docs/specs/compact_one_requirement_baseline.md` 为准；外置参考模型位于
> `external_version/infrontofSamuraiMag/`。

## 1. 文档目标与范围

本文整理 RCNP（大阪大学核物理研究中心）WS 束流线 BLP（Beam Line Polarimeter）相关公开资料中的机械与工艺要点，面向本项目 FreeCAD 建模使用。重点关注：

- BLP 在 WS 束流线中的位置与功能
- 散射室开孔、窗口、密封与真空接口
- 靶梯（target ladder）与线性馈入机构
- 探测器几何与支撑思路
- 与本仓库 legacy external `infrontofSamuraiMag` 参考参数的历史映射

本文不替代 RCNP 内部工程图纸；公开资料缺失的尺寸会明确标注为“待定参数”。

## 2. 已确认的核心几何与实验事实

### 2.1 BLP 几何与测量模式

- WS 束流线上使用 BLP1/BLP2 监测束流状态与极化，BLP 在设施布局图中有明确标注 [2][3][4]。
- BLP 水平面几何采用散射-反冲符合计数，典型角度为：
  - 散射角约 `17.0°`
  - 反冲角约 `69.7°` 或 `70.5°`（不同文献/版本略有差异）[2][3][4][5]。
- BLP 使用塑料闪烁体对（L/R/U/D）进行符合测量 [2][3][5]。

### 2.2 分析靶信息（公开文献）

- 曾使用 `CH2` 与 aramid（芳纶）作为分析靶 [2][3][4]。
- 文献中可见如下量级：
  - CH2 面密度：约 `8.4 mg/cm²`
  - aramid 面密度：约 `5.0 mg/cm²`
  - 另有薄膜厚度级别 `4 μm` 的 aramid 描述 [2][3]。

### 2.3 相关窗口与薄膜参数（公开文献）

注意：以下窗口参数中，部分来自 GR/VDC/气体靶系统，不全是“BLP 本体出射窗”直接尺寸，但对材料和薄膜工艺有直接参考价值。

- `Entrance/exit window`: `12.5 μm` aramid 或 carbon-aramid 薄膜 [3][5]。
- VDC cathode：`10 μm` carbon-aramid 薄膜 [3][5]。
- 气体靶 cell 示例：aramid 窗厚 `6 μm`，窗口尺寸约 `58W × 28H mm²` [2]。

## 3. 散射室机械设计要点（可直接映射到 CAD）

### 3.1 室体与主束流通道

- 室体形态：公开资料中可见“箱式/紧凑散射室”工程图与照片 [6]。
- 主束流轴应保留入口/出口通道，且出口可适度放大以降低边缘打束风险（工程上常用的背景抑制策略）。
- 材料优先非磁/弱磁不锈钢（如 304/316L）。

建议建模字段（参数化）：

| 参数 | 建议类型 | 当前值状态 |
|---|---|---|
| chamber 外形尺寸 | mm | 待定（由现场安装空间反推） |
| 壁厚 | mm | 待定 |
| 束流入口孔径 | mm | 参考级别：80–100（需现场确认） |
| 束流出口孔径 | mm | 建议不小于入口 |
| 入口/出口法兰标准 | 枚举 | 待定（CF/ISO 需选型） |

### 3.2 散射粒子窗口

- 窗口开孔应按运动学方向布置（至少覆盖 L/R 对；若包含 U/D 则补充垂直平面窗口）。
- 窗口结构建议采用：
  - 室壁开孔
  - 压环（retaining ring）
  - 薄膜（Kapton/aramid 方案二选一，按真空与散射损失折中）
- 薄膜厚度选型建议在文献可见范围内选点，并通过强度校核后定版。

建议建模字段：

| 参数 | 建议类型 | 当前值状态 |
|---|---|---|
| 窗口中心角度（水平） | deg | 可用：17.0, 69.7/70.5 相关几何派生 |
| 窗口开孔直径/扇角 | mm/deg | 待定 |
| 薄膜材料 | 枚举 | Kapton / aramid（待定） |
| 薄膜厚度 | μm | 参考级别：6, 10, 12.5 |
| 压环外径与厚度 | mm | 待定 |

### 3.3 真空接口

应预留：

- 泵口（涡轮分子泵）
- 真空计口
- 安全泄压/检修口

这些接口在 CAD 中应作为独立零件或标准件占位体，便于后续替换为具体法兰标准。

## 4. 靶梯（Target Ladder）与馈入机构

公开资料支持“多靶位 + 线性馈入”的结构思路 [2][6]。可按五槽位方案建模：

| 槽位 | 功能 | 典型内容 |
|---|---|---|
| 1 | 分析靶 | CH2 / aramid |
| 2 | 标定靶 | C 靶 |
| 3 | 观察屏 | 荧光屏 |
| 4 | 空框 | empty frame |
| 5 | 直通 | no target |

机构要点：

- 垂直导向（双导轨）
- 顶部线性馈入杆
- 波纹管真空隔离段
- 目标定位重复精度指标（工程目标）建议优于 `0.1 mm`（最终需实验团队确认）

## 5. 探测器与支撑结构

### 5.1 legacy external 历史约束（非当前 compact 基线）

保留的旧外置路线曾采用“探测器外壳为直径 `50 mm` 圆柱，前表面中心位于给定角度与半径”的包络：

| 粒子通道 | 角度（lab） | 半径 |
|---|---:|---:|
| deuteron | 20.9° | 0.40 m |
| proton-1 | 11.2° | 0.62 m |
| proton-2 | 53.4° | 0.62 m |

这三组是 legacy external 布置的历史参考，既不是 RCNP 原始 BLP 的一一复刻参数，
也不是当前 CompactInVacuum 配置。当前 compact 原型采用 20 mm 有效直径，通道有效中心半径为
140/190/205 mm，其状态和证据等级由专用基线与 resolved configuration 管理。

### 5.2 支撑建模建议

- 每个探测器至少包含：壳体、前端有效面、支撑杆、锁紧环。
- 支撑杆应从腔体壁面/窗口环引出，并预留长度调节余量。
- 建议为每个探测器对象写入属性：`AngleDeg`, `RadiusMM`, `FrontFaceConstraint`，方便后续自动校核。

## 6. 准直器与背景抑制

- 上游可配置铜准直器，文献中常见 `5 mm` 厚度量级 [7]。
- 准直孔径应与束斑和计数率目标联调；建议在 CAD 中独立建“可替换孔径插片”结构。

## 7. 公式与数据处理（简要）

极化计常见左右不对称定义可写为：

`epsilon = (N_L - N_R) / (N_L + N_R)`

并结合分析力 `A_y` 估算极化分量：

`P ≈ epsilon / A_y`

具体修正项（效率、背景、传输修正）应以对应实验论文分析章节为准 [2][3][5]。

## 8. 对本仓库 CAD 的落地建议

以下只是对 `external_version/infrontofSamuraiMag/` 外置参考路线的历史建模方法：

1. 采用“参数化装配”而非单体布尔模型。
2. 腔体、法兰、窗口环、薄膜、靶梯、馈入、探测器支撑全部拆为独立对象。
3. 所有关键尺寸写为脚本参数，禁止硬编码散落。
4. 导出 `FCStd + STEP` 两份，并保留对象命名语义化（便于审阅与二次开发）。

## 9. 当前缺失与待确认参数

以下内容在公开资料中缺乏“可加工级尺寸链”，需后续补充：

- BLP 本体散射室完整二维工程图（含法兰标准、孔系、公差）
- BLP 独立窗口组件（压环螺栓孔、预紧方式、膜片固定细节）
- 探测器支架装配图（调角机构、锁定方式、重复定位指标）
- 靶梯电机与丝杠规格（导程、扭矩、安全行程）

---

## 参考文献

[1] RCNP, Nuclear Science 1A Facilities. https://www.rcnp.osaka-u.ac.jp/Divisions/np1-a/facilities.html (accessed 2026-02-23).

[2] Matsubara, PhD Thesis (2010), RCNP. https://www.rcnp.osaka-u.ac.jp/Divisions/np1-a/thesis/Matsubara_PhD2010.pdf (accessed 2026-02-23).

[3] Nakamura, Master Thesis (2018), RCNP. https://www.rcnp.osaka-u.ac.jp/Divisions/np1-a/thesis/Nakamura_master2018.pdf (accessed 2026-02-23).

[4] Matsubara, Master Thesis (2005), RCNP. https://www.rcnp.osaka-u.ac.jp/Divisions/np1-a/thesis/Matsubara_master2005.pdf (accessed 2026-02-23).

[5] Zenihiro, PhD Thesis (2011), RCNP. https://www.rcnp.osaka-u.ac.jp/Divisions/np1-a/thesis/Zenihiro_PhD2011.pdf (accessed 2026-02-23).

[6] I Ou, PhD Thesis (2017), RCNP (Appendix B drawings). https://www.rcnp.osaka-u.ac.jp/Divisions/np1-a/thesis/IOu_PhD2017.pdf (accessed 2026-02-23).

[7] RCNP WS beam line note (CYC2001). https://epaper.kek.jp/c01/cyc2001/paper/P1-17.pdf (accessed 2026-02-23).

[8] RCNP WS beam line page (BLP sections). https://www.rcnp.osaka-u.ac.jp/Divisions/np1-a/ws/index.html (accessed 2026-02-23).

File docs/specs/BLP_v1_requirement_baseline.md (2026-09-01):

# BLP Mechanical Requirement Baseline v1

## 1. Purpose
本文件是 `external_version/afterSRC/` 与 `external_version/infrontofSamuraiMag/` 外置探测器机械路线的需求基线，用于跨终端一致协作与上下文连续性。

当前项目基线不是“afterSRC 外置 + 一台 CompactInVacuum”，而是两台真空内紧凑型极化仪：`CompactInVacuum-afterSRC` 与 `CompactInVacuum-preSAMURAI`。`external_version/afterSRC/` 外置探测器设计仅作为 legacy/fallback/reference 路线保留。

CompactInVacuum 公共平台及两台基线仪器由 `docs/specs/compact_one_requirement_baseline.md` 管理。本文件中已有 CompactInVacuum 条目仅作为迁移历史、筛选假设和外置路线接口关联说明；若两者冲突，以 CompactInVacuum 专用基线为准。

## 2. Frozen Decisions
- target chamber 不使用圆锥过渡。
- `infrontofSamuraiMag` 与 `afterSRC` 外置探测器家族：探测器全部位于 chamber 外部；chamber 不提供探测器信号穿腔接口。
- 外置探测器家族三板拓扑：H+V+V，且三块板均偏离束流中心轴。
- 外置参考设计保持 12 个位点（3 通道 × 上下左右）；CompactInVacuum 公共平台同样采用 12 个真空内通道，但不使用外置 H+V+V 板。
- 探测器夹具：两半抱箍，轴向分型；固定角度过渡块；全固定（无调节）；抱箍锁紧螺钉必须布置在探测体圆柱外侧两侧，不允许任何锁紧螺钉轴线穿过探测器圆柱包络或抱箍内孔中心带。
- 探测器夹具与板连接采用“探测器 + 抱箍 + 过渡块 + 桥接件 + 底座”共享同一局部刚体坐标系后整体旋转落板；板上 4 孔矩形由该刚体总成方向带出确定打孔位置”，不使用杆件支撑。
- 探测器夹具安装拓扑冻结为“底座 + 双立板 + 顶部桥接件 + 过渡块”，其中整套夹具相对探测体圆柱保持刚性参考关系，底座必须与夹具形成连续承载路径。
- 探测器夹具下部承载语义冻结为“仅支撑侧半抱箍带下侧平鞍座”，该平鞍座必须与过渡块直接贴合形成连续实体承载路径；非承载半抱箍仅负责压紧，不得长出下部承载实体；`detector.adapter_block.radial_standoff_mm` 字段保留但严格口径固定为 `0.0`。
- 探测器夹具承载件语义进一步冻结为“支撑侧半抱箍 + 过渡块 + 双立板 + 顶桥”为一体承力件；与板件连接的四孔底座板保持独立螺接件，不再把承载侧主路径拆成多个彼此贴合的分体件。
- 外置路线当前可生成、可严格验证的夹具继续由 `geometry.detector.active_fixture=external_reference_v1_31` 明确选择，并由 `external_reference_fixture` 保存最后一次 strict-pass 参数。v1.33 双半板夹具保留为独立原型 schema/零件生成器；在完成整机落位、承载路径、紧固件、干涉和 strict gate 集成前，不得替换当前外置路线，也不得被描述为已验证工程夹具。
- 板件支撑语义冻结为“无 plate-tie 拉杆”：探测器夹具底座直接固定到板件，不引入板-底座间附加拉杆件。
- 当前照片式支撑方案不使用整体大底板；stand 只保留独立支撑脚、调平螺钉与垫片，不再保留覆盖三板下方的 monolithic stand base plate。
- 防转/防滑：机械限位肩 + 端面止挡。
- 板件防遮挡：按“有效靶心 -> 探测器有效面”的真实 LOS 管道做布尔让位；只切除与该 LOS 管道真实相交的板体材料，不允许用探测器到板面的正交投影去连成连续槽口；margin=5 mm。
- 三板全实体外置于 chamber 外部，板件与 chamber 不允许实体重叠；必要时通过挖孔/让位确保装配无干涉。
- 板件切除语义冻结为“只为 chamber 真实让位和 LOS/target 工作空间开口”；底座、支撑脚以及板与底座之间的结构区域不得驱动板体切除。
- 当 `H` 板贴近 `-y` 侧 chamber 时，如与 `down` 三个探测器包络或其“靶心 -> 探测器前表面圆”真实圆锥 LOS 相交，必须在 `H` 板上生成局部长方形让位孔；该矩形让位窗必须覆盖圆锥与板厚带的真实相交投影，禁止退化成仅按板中面圆截面估算的过小开口，也禁止把无关区域连成连续槽。
- 板位策略采用半自动：支持 `offset_mode=auto/manual`，自动模式按“最小外置 + safety gap”求板法向偏置，板内平移保留人工控制。
- 照片式板位冻结：`H` 板位于 `-y` 侧；`V1/V2` 保持 `+x/-x` 对称，并采用“首个 strict-pass 内收值 + 5 mm 制造裕量”的手工偏置。
- V1/V2 板净间距约束：净间距 >= 2 × 探测器外径（按 clamp 外径口径）。
- chamber 核心体采用细长长方体：当前 strict side-exit 基线 `chamber.core.size_x_mm=185.0`、`chamber.core.size_y_mm=185.0`、`chamber.core.size_z_mm=1200.0`、`chamber.core.center_z_mm=400.0`，即有效前后端面落在 `z=[-200.0,+1000.0] mm`，保持工作靶心左侧空间不再继续增加，同时把右侧后端沿束线方向再拉长约 `300 mm`；垂直 z 的横向尺度继续保持收紧，使 12 条通道优先从 `±x / ±y` 四个侧面出腔，而不是先撞 `+z` 面。
- chamber 侧向探测通道的开孔语义冻结为“有效靶点中心 -> 探测器前表面圆”的圆锥包络切腔；禁止再用固定直径圆柱近似整条 side-exit 通道。
- 靶机构：单靶旋转式，不再使用 3 位线性靶梯。
- 靶框：单靶可拆框架，双螺钉压板锁定。
- 驱动：电机在真空外，纯机械旋转馈通；机械止挡 + 计步校准；外部手轮应急；工作位使靶心落在束流中心，停靠位使整套 holder 偏心摆离 z 轴束流包络。
- 真空接口采用模块化合同冻结：`infrontofSamuraiMag` 保持前后 JIS 可更换模块，默认上游 `VF100` / 下游 `VG80`，接口装配语义为 `[ chamber ] -> welded round pipe stub -> [ flange ] <-> [ mating flange / equipment ]`；当前默认上游 stub 长 `100 mm`、下游 stub 长 `20 mm`；`VG` 侧在对外接口面带 O-ring groove，`VF` 侧不带 groove。
- legacy `external_version/afterSRC/` 外置路线的历史真空接口合同为：前后束流端面 `ICF114`，顶部旋转馈通安装面 `ICF70`。该合同只约束 legacy 外置设计，证据类别为 `B — LEGACY INHERITANCE`，不得自动传播到 `CompactInVacuum-afterSRC`。
- CompactInVacuum 历史 CAD 中的前后 `ICF114`、顶部 `ICF70` 为筛选/集成假设，不是已确认束线约束。两台 CompactInVacuum 的束流配合接口当前均为 `D — UNRESOLVED/TBD`；afterSRC compact 的 ICF114/ICF70 外形研究按 `B/C` 管理，直到独立的束线图纸、现场测量或责任方批准将其提升为 `A — EXTERNAL CONSTRAINT`。
- CompactInVacuum 公共电气服务需求为“真空内无有源模拟电子学”：每个 SiPM 使用一条独立、可测试的 `50 Ω` 同轴通道，信号与偏置通过真空外 bias tee 共线；12 路使用，每扇区 1 路备用容量仅为建议。专用温度传感器、温度线束、housekeeping 通道及多芯 housekeeping 馈通不是公共平台需求，并已由 CompactInVacuum schema 3 删除。四个四通道 `ICF70` 同轴口仅为 `C — ENGINEERING ASSUMPTION`，具体法兰标准、数量、位置、连接器、真空电缆、料号和通道分配均由两台仪器分别关闭。
- CompactInVacuum 馈通与线缆宜集中在可维护的服务区。所有外置馈通器按可拆采购件处理，运输状态应能拆除并用同真空等级盲板封闭；焊接短管、购买件密封、转接器、波纹管、馈通器和整机焊缝共同构成验收真空边界，不允许用未经批准的低等级密封替代。具体 ICF/CF/JIS 标准由每个站点的已批准接口证据决定。
- `CompactInVacuum` 真空内布线必须有参数化路由包络、靠近探测器和馈通端的机械应力释放、独立保护接地/等电位连接以及束流和旋转靶 keep-out。供应商电缆未冻结前，概念 CAD 使用 `25 mm` 最小静态弯曲半径和 `8 mm` 路由包络直径；这些值是待电缆图纸验证的设计假设，不是采购规格。
- chamber 端口按模块化合同冻结：`infrontofSamuraiMag` 保持主泵口 + 真空计/安全口 + 机械旋转馈通口 + 备用口（固定 4 口）；`afterSRC` 仅保留顶置 `rotary_feedthrough`，不再保留 `main_pump / gauge_safety / spare` 侧口；允许端口在所属壁面内做偏心布置以服务新 target rotary 机构。
- 主泵口在右侧；真空计/安全口在对侧。
- chamber 安装：放置于水平主板，改为 chamber 自支撑四柱 + `H` 板独立四柱，共 `8` 个支撑脚。
- 八支撑脚投影布局冻结为“两组独立四柱网格”：target chamber 自带 `4` 根支撑柱，位于 `x=±60 mm` 且 `z` 分别距离前后端面 `50 mm`；按当前基线即 `z=-150 mm` 和 `z=+950 mm`。`H` 板再由另外 `4` 根独立支撑柱承托，当前 strict 基线冻结为 `x=-24±200 mm`、`z=400 mm / 840 mm`，用于把 chamber 与 `H` 板的承载路径拆开并降低大板变形风险。
- 支撑高度语义冻结：stand 的落地基准必须由支撑柱给出，不允许 `V1/V2` 板先接地；当前基线要求支撑脚底面低于两块 `V` 板的最低 `y` 边界。
- 整机支架：地脚螺栓 + 长孔找正；调平螺钉 + 垫片；维护方向以上方与左右侧为主。

## 3. Coordinate and Geometry Basis
- 束线主轴：Z 轴。
- 单靶工作位有效靶心：原点 `(0, 0, 0)`。
- chamber 核心体：长方体（独立三轴尺寸）。
- chamber 前后统一接口面：平面密封，圆形螺栓阵列接口。
- 通道首出腔面（冻结）：
  - `left -> -x`
  - `right -> +x`
  - `up -> +y`
  - `down -> -y`
- 三板姿态语义（冻结）：
  - `plate.h`: `orientation=horizontal`, `mount_plane=xz`
  - `plate.v1`: `orientation=vertical`, `mount_plane=yz`
  - `plate.v2`: `orientation=vertical`, `mount_plane=yz`
- 扇区到板件映射（冻结）：
  - `left/right -> plate.h`
  - `up -> plate.v1`
  - `down -> plate.v2`

## 4. Parameterization Rules
- 命名：分组点号命名（如 `chamber.core.size_z_mm`）。
- 单位：长度 mm，角度 deg。
- 参数分组：
  - beamline
  - chamber.core
  - chamber.end_modules
  - ports
  - plate.h / plate.v1 / plate.v2
  - detector.clamp
  - detector.adapter_block
  - target.mode
  - target.rotary
  - target.single_holder
  - stand
  - clearance
- 布局：`layout.channels[]` 显式通道表。
- 初值策略：可按旧图估算，但每个估算值需标注 confidence（high/medium/low）。

## 5. Validation Gate
LOS scope definition (frozen contract):
- LOS_v1_scope=概念几何遮挡检查（plate/port/stand 级遮挡）
- LOS_v2_scope=全路径物理无遮挡（源面 -> 腔体内有效通道 -> 探测器有效面）
- 当前冻结口径（本轮关账） = LOS_v1_scope

通过条件必须同时满足：
- 角度/半径命中
- LOS 无遮挡（v1 概念几何范围：plates / ports / stand；豁免：chamber_shell / end_modules / target_hardware / detector_packages）
- 无实体干涉（至少覆盖 detector package 对主装配碰撞矩阵）
- 真空边界完整
- CompactInVacuum 通用验证要求：12 条已分配同轴通道可追踪；建议的 4 条备用容量状态明确；不得因 schema 3 已删除的温度或 housekeeping 子系统缺席而失败；线缆路由包络不进入束流 stay-clear 或旋转靶工作/停靠包络；馈通端与探测器端均有应力释放；外部馈通器包络不得与相邻法兰或维护抽取包络重叠。束流与旋转接口必须按各部署配置核对；未获 `A — EXTERNAL CONSTRAINT` 证据时，strict release gate 必须保持未关闭，不得硬编码为 ICF114/ICF70 通过。

## 6. Required Artifacts
- FCStd
- STEP
- JSON 验收报告（按子系统汇总：chamber / plates / detector / target / stand）

## 7. Change Control
- 本文件为 v1 基线，修改必须追加版本记录，不覆盖历史决策。

## 8. Version History
- 2026-09-01 v1.36:
  - 将 CompactInVacuum 专用温度监测、housekeeping 通道和多芯馈通从当前公共需求中删除，与 `compact_one_requirement_baseline.md` 和 schema 3 保持一致。
  - 保留 v1.32/v1.35 版本记录作为迁移历史，不将其中的旧监测要求解读为当前合同。
- 2026-07-27 v1.35:
  - 更正顶层项目架构：当前基线为 `CompactInVacuum-afterSRC` 与 `CompactInVacuum-preSAMURAI` 两台真空内紧凑型仪器；`afterSRC/` 外置设计降为 legacy/fallback/reference。
  - 将 CompactInVacuum 的 ICF114/ICF70 从“固定合同”更正为继承/工程假设；两站点束线接口在取得独立图纸、测量或责任方批准前保持 TBD。
  - 保留 12 路 50 Ω 同轴、外置 bias tee、温度监测和备用容量等公共探测器平台需求，同时把具体馈通法兰标准、数量和位置改为站点特定决策。
- 2026-07-27 v1.34:
  - 记录并隔离未完成的 v1.33 双半板夹具迁移：新 schema 与上下半板独立原型继续保留，但不再让它们破坏 `afterSRC` / `infrontofSamuraiMag` 已验证外置路线。
  - 新增显式 `active_fixture` 与 `external_reference_fixture` 合同；当前 active 值冻结为 `external_reference_v1_31`，直到 v1.33 完成整机集成和严格验证后再走受控切换。
- 2026-07-26 v1.32:
  - 将原有“探测器全部位于 chamber 外部”的范围明确限定为 `infrontofSamuraiMag/afterSRC` 外置家族，并登记 `CompactInVacuum` 为 12 路真空内 SiPM 主要开发版本。
  - 冻结 `CompactInVacuum` 前后 `ICF114` 和顶部靶旋转 `ICF70` 安装接口；供应商旋转馈通的载荷、扭矩、寿命及详细外形继续保持待 RFQ。
  - 建立四方位、每方位一个四通道 `ICF70` 同轴馈通的概念架构，12 路使用、4 路备用；信号与 SiPM 偏置共用同轴并在真空外通过 bias tee 分离。
  - 增加一个不少于 32 针的 `ICF70` housekeeping 馈通、12 个两线温度通道、独立接地、应力释放、`25 mm` 暂定最小弯曲半径和运输拆卸/盲板合同。
- 2026-04-08 v1.31:
  - 探测器夹具承载侧从“下半抱箍与过渡块/立板/桥接件直接接触的分体路径”收紧为“下半抱箍 + 过渡块 + 双立板 + 顶桥”的单件承力体。
  - 板侧 4 孔底座板继续独立保留为螺接安装件，形成“单件承载上体 + 独立底座板”的加工/装配语义。
- 2026-04-08 v1.30:
  - 探测器夹具下部承载路径从“抱箍附近过渡块”收紧为“仅支撑侧半抱箍下侧平鞍座 -> 过渡块 -> 双立板/桥接件 -> 底座”的连续实体路径。
  - `detector.adapter_block.radial_standoff_mm` 保留字段但严格口径固定为 `0.0`，禁止再在抱箍与下方支撑之间保留可见缝隙。
- 2026-04-08 v1.29:
  - 探测器夹具语义从“bridge-to-detector rigid pose”收紧为“detector + clamp + adapter + bridge + base 共享同一局部刚体坐标系并整体旋转落板”，禁止再按板法向对夹具子件做二次相对求姿。
  - 抱箍锁紧螺钉冻结为“圆柱外侧两侧切向夹紧”语义；螺钉轴线不得穿过探测器包络或抱箍内孔中心带。
- 2026-03-27 v1.28:
  - 将真空接口与端口规则改为按模块冻结：`infrontofSamuraiMag` 继续使用 `front=VF100 / rear=VG80 + fixed 4 ports`。
  - 新增 `afterSRC` 合同：`front=ICF114 / rear=ICF114`、顶置 `ICF70` 旋转馈通直连、禁用 `main_pump / gauge_safety / spare` 侧口。
  - `afterSRC` 束流通径按 `ICF114/DN63CF` 兼容口径收紧，不再沿用 `80 mm` 基线。
- 2026-03-27 v1.27:
  - 按最新装配意见，`H` 板独立四柱在 `x` 方向再略向外展开；当前冻结为 `x=-24.0±200.0 mm`，`z=400.0/840.0 mm`。
- 2026-03-27 v1.26:
  - chamber 四柱的前后端面内缩量从 `100 mm` 改为 `50 mm`，当前冻结为 `z=-150.0/+950.0 mm`，继续保持 `x=±60.0 mm`。
  - stand 支撑高度进一步加长，冻结语义为“支撑脚先落地，`V1/V2` 板不得先碰地”；当前 runtime 校验要求支撑脚底低于两块竖板的最低 `y` 边界。
- 2026-03-27 v1.25:
  - 右侧后端沿束线方向再加长约 `300 mm`，strict side-exit chamber 更新为 `size_z_mm=1200.0`、`center_z_mm=400.0`，对应前后端面 `z=[-200.0,+1000.0] mm`。
  - stand 从原先“chamber/H 共用四脚”切换为“chamber 自支撑四脚 + H 板独立四脚”共八脚布局；chamber 四脚冻结在 `x=±60.0 mm, z=-100.0/+900.0 mm`，`H` 板四脚冻结在 `x=-24.0±160.0 mm, z=400.0/840.0 mm`。
- 2026-03-26 v1.24:
  - `H` 板局部长方形让位窗的 LOS 口径收紧为“真实靶点 -> 探测器前表面圆”圆锥与板厚带的相交包络，禁止再用板中面圆截面近似，以免残留材料挡住圆锥通道。
  - 应最新装配观察，将前方那对 chamber-side 支撑脚从 `z=-200.0 mm` 回调到 `z=-150.0 mm`；`H` 板支撑排继续保持 `z=620.0 mm, x=-24.0±160.0 mm`。
- 2026-03-26 v1.23:
  - 应最新装配观察，将前方那对 chamber-side 支撑脚继续朝上游方向移动 `100 mm`，当前冻结为 chamber row `z=-200.0 mm, x=±50.0 mm`；`H` 板支撑排继续保持 `z=620.0 mm, x=-24.0±160.0 mm`。
- 2026-03-26 v1.22:
  - 四支撑脚从“远角底座投影”改为“两排居中支撑”：2 根落在 target chamber footprint 内、2 根落在 `H` 板 footprint 内，减少 `H` 板跨距与变形风险。
  - 当前 strict 基线冻结为 chamber row `z=250.0 mm, x=±50.0 mm`，H row `z=620.0 mm, x=-24.0±160.0 mm`。
- 2026-03-26 v1.21:
  - 按最新视觉要求，strict side-exit chamber 的左侧端面进一步缩到 `z=-200.0 mm`，右侧端面保持 `z=+700.0 mm`，因此核心体更新为 `size_z_mm=900.0`、`center_z_mm=250.0`。
  - 为保持固定四端口既落在缩短后的壳体侧壁范围内、又不遮挡左右通道 LOS，`main_pump / gauge_safety / spare` 的 `center_z_mm` 调整为 `-120 / -140 / -160 mm`。
- 2026-03-26 v1.20:
  - 为保留靶子右侧现有空间、缩短左侧过大空腔，strict side-exit chamber 的 z 向核心体改为不对称布置：`size_z_mm=1300.0`、`center_z_mm=50.0`，对应前后端面 `z=[-600.0,+700.0] mm`。
  - 前端 `VF100` 法兰与 chamber 之间的焊接圆管显著加长到 `100 mm`；后端 `VG80` 焊接圆管继续保持 `20 mm` 不变。
- 2026-03-26 v1.19:
  - chamber 前后真空接口装配语义切换为“腔体短管焊接到 JIS flange，再由 JIS flange 与外部 mating flange / equipment 螺栓连接”；默认 stub 长度冻结为上游 `10 mm`、下游 `20 mm`。
  - 当前 strict side-exit chamber 横向尺寸进一步收紧，冻结为 `chamber.core.size_x_mm=185.0`、`chamber.core.size_y_mm=185.0`，并保持工作靶心在 `(0,0,0)`。
- 2026-03-26 v1.18:
  - 当前 strict side-exit chamber 基线沿束线方向在 `1300.0 mm` 基础上再加长 `100 mm`，冻结为 `chamber.core.size_z_mm=1400.0`。
- 2026-03-26 v1.17:
  - chamber side-exit detector openings 从固定直径 LOS 圆柱切腔改为“有效靶点中心 -> 探测器前表面圆”圆锥包络切腔；rear end module 同步按该圆锥贯通开口。
- 2026-03-26 v1.16:
  - 默认真空接口从“上游 `VG150` / 下游 `VF80`”切换为“上游 `VF100` / 下游 `VG80`”，继续保持 `VG` 带 groove、`VF` 不带 groove 的类型语义。
  - 当前 strict side-exit chamber 基线沿束线方向再加长 100 mm，冻结为 `chamber.core.size_z_mm=1300.0`。
- 2026-03-23 v1.15:
  - 删除当前照片式支撑方案中的 monolithic stand base plate，冻结为“四支脚 + 调平螺钉 + 垫片”支撑。
  - `H` 板内收贴近 chamber 后，若与下方三路探测器包络或其真实 LOS 相交，改用局部长方形让位孔处理，不得切掉底座之间的整片区域。
- 2026-03-23 v1.14:
  - 板件开口口径从“板面投影连续槽”切换为“靶心到探测器的真实 LOS 管道布尔让位”，禁止再按 detector-to-plate projection 连接不同底座之间的空区。
- 2026-03-23 v1.13:
  - `H` 板从 `+y` 翻到 `-y` 服务侧，三块板按“首个 strict-pass 内收值 + 5 mm 制造裕量”重新冻结为更贴近 chamber 的照片式布局。
  - 板体切除语义冻结为“只为 chamber 真实让位和 LOS/target 工作空间开口”，禁止底座/支撑区域驱动大面积切板。
- 2026-03-19 v1.10:
  - 探测器安装语义更新为“bridge-to-detector rigid pose + fixture-driven drilling”；板上 4 孔矩形由总成方向带出，不再以板局部轴作为唯一孔位朝向基准。
  - 保留 `base + uprights + top bridge + adapter block` 连续承载路径，但允许立板长度随目标板法向落板位置变化。
- 2026-03-22 v1.11:
  - chamber 核心体冻结为“沿 z 拉长、横向收窄”的细长长方体；12 条通道首出腔面冻结为 `left/right/up/down -> -x/+x/+y/-y`。
  - 靶机构冻结为“单靶 + 顶置 Y 轴旋转 + 偏心摆出停靠”，删除当前活动设计中的 `3-position linear ladder` 冻结语义。
  - `ports` 参数允许在所属壁面内偏心定位，以支持 `rotary_feedthrough` 服务偏心单靶转轴。
- 2026-03-23 v1.12:
  - 三块板的探测器通道开口冻结为连续圆角槽口，不再使用会留下角落残片的扇形环带布尔切法。
  - `+z` 端下游接口冻结为 `VF80`，上游接口继续保持 `VG150`；`VG/VF` 的 groove 语义按类型区分而不是按前后位置写死。
- 2026-03-06 v1.9:
  - 冻结 `legacy_center_preview_locked` 阶段基线：三板按当前对齐坐标与尺寸固定，用于后续小步调参。
  - 预览阶段 `target.validation.strict=false`，保留报告输出但不阻断迭代节奏。
- 2026-03-06 v1.8:
  - 新增一次性“旧版板位预览模式”约束：允许将三板按 old-version 尺寸/坐标复刻用于视觉迭代。
  - 预览模式下允许关闭板件开孔与切让位（`disable_plate_cuts=true`），并跳过重叠类校验（`skip_overlap_checks=true`）。
  - 该模式仅用于几何比对与迭代，不作为最终关账口径。
- 2026-03-06 v1.7:
  - 冻结“无 plate-tie 拉杆”约束：夹具底座直接固定到板件。
  - LOS_v1 概念遮挡范围更新为 `plates / ports / stand`（不再含 `plate_ties`）。
- 2026-03-06 v1.6:
  - 冻结夹具安装拓扑：`base + uprights + top bridge + adapter block`，禁止“独立浮置底座”。
  - 新增 detector 子系统验收项：结构连续性、扇区落板映射、桥接长度上限。
  - 冻结板位“半自动”策略：`offset_mode=auto/manual` 与 `clearance.plate_auto_gap_mm`。
- 2026-03-06 v1.5:
  - 冻结三板法向语义：`H ⟂ Y (xz)`，`V1/V2 ⟂ X (yz)`。
  - 冻结板件分配：`left/right->h`，`up->v1`，`down->v2`。
  - 冻结探测器安装语义：沿板法向正交投影落板，4 孔矩形螺栓固定，禁用杆件支撑。
  - 冻结板件外置语义：三板全实体位于 chamber 外部。
  - 无实体干涉口径补充：v1 概念阶段 detector-package 碰撞矩阵豁免 `plate_ties`。
- 2026-03-06 v1.4:
  - 新增板件与 chamber 零重叠约束，要求通过板件挖孔实现。
  - 新增 V1/V2 净间距下限：`>= 2 * detector.clamp.outer_diameter_mm`。
- 2026-03-06 v1.3:
  - 冻结三板姿态坐标语义：`H=xy`，`V1/V2=yz`。
  - 冻结扇区到板件映射：`up/down->h`，`left->v1`，`right->v2`。
- 2026-03-05 v1.1:
  - 明确 LOS 验收的 v1 概念几何范围与豁免集合（见第 5 节）。
  - 明确“无实体干涉”至少覆盖 detector package 对全装配碰撞矩阵。
- 2026-03-05 v1.2:
  - 新增 `LOS_v1_scope` / `LOS_v2_scope` 显式定义。
  - 冻结本轮交付口径为 `LOS_v1_scope`，并明确 v2 为后续全路径物理无遮挡口径。

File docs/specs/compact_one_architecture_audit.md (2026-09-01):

# CompactInVacuum Architecture Audit

> Status: dated implementation snapshot from 2026-07-29. It is not a requirement authority.
> `compact_one_requirement_baseline.md` and the current resolved deployment configuration supersede
> any conflicting dimension, access, support, or extraction statement below.

## Audit scope

Audit date: 2026-07-29

Implementation branch: `redesign/compact-detector-holder-v2`

Baseline deployments:

- `CompactInVacuum-afterSRC`
- `CompactInVacuum-preSAMURAI`

Preserved external routes remain outside the redesign scope. No file in the legacy afterSRC or SAMURAI-front external implementations is intentionally changed.

## Diagnosis of the superseded design

The former common detector package was mechanically misleading:

- a 5.5 mm active plastic was placed inside a 35 mm nose and 44 mm rectangular cassette;
- the SiPM/optical readout relationship was visually lost inside oversized packaging;
- a long `CassetteThermalBridge` existed to satisfy an abstract graph rather than a credible conductive assembly;
- every detector had its own mount pad, long wall rail, wall anchor, and cylindrical thermal strap;
- the three channels did not form one serviceable sector mechanism;
- temperature sensors, four temperature harnesses, twelve required channels, and a housekeeping feedthrough were treated as mandatory despite no current platform requirement;
- physical objects, keepouts, datums, service paths, and acceptance volumes opened together as one visually confusing assembly.

Passing geometric tests did not make the support manufacturable or the detector package credible.

## Implemented architecture

### Detector head

The detector is now an explicit short axial stack:

`active plastic -> optical coupling -> SiPM package -> sensor PCB/carrier -> rear mounting face`

A thin reflector envelope surrounds the active plastic. A shallow light-tight sleeve and rear face replace the long nose and box. The default housing depth is calculated as 9.70 mm and is below the 18 mm gate. Cable exit and connector keepout remain separately classified and excluded from this depth.

The protruding anti-rotation key initially shadowed a neighboring proton acceptance volume during redesign validation. It was replaced by a rear-flange D-flat and matching nest land.

### Sector holder

Each sector now has one connected carrier plate, three rear nests, three insertion stops, three removable clamp bridges, six simplified M3 fastener envelopes, a common rear cable lane, and one plane–pin–slot chamber interface.

The carrier is relieved against all three complete-disc acceptance volumes. Fasteners are oriented along the local azimuthal tangent so they do not enter a neighboring channel’s cone. Each detector has a 12 mm sampled rearward withdrawal path after clamp release. At the audit date, each sector also had five exact solid poses along a 70 mm radial comparison path. That path has since been superseded for the afterSRC fixed-wall/ICF305 design: current exact poses establish only the first 12 mm support-release stage, not complete translation, reorientation, or lift through the maintenance port.

The displayed extraction boxes are diagnostic overlays. Exact holder solids are used for collision validation.

### Services and thermal semantics

Only rotary and signal service-port roles remain. The dedicated monitoring system and housekeeping feedthrough are removed.

The passive conductive contract follows actual contacting parts:

`SiPM -> carrier -> rear face -> nest -> sector plate -> chamber interface`

No artificial long thermal bridge remains.

### Display architecture

Every generated object is assigned one of seven engineering roles. Only physical and purchased-component/interface objects are visible by default. Keepouts, datums, service centerlines, acceptance volumes, and optional references are hidden.

Documents are grouped by detector head, sector holder, target, services, chamber, keepouts, datums, and physics acceptance as applicable.

## Retained architecture

- Four sectors and three configured channels per sector.
- Twelve active detector faces.
- Target-centered axes and active-center radius semantics.
- Repository channel angles and coincidence pairing.
- Complete target-to-active-disc acceptance construction.
- Target WORK/PARK motion semantics.
- Square and cylindrical deployment chamber candidates.
- Stateful generation and stable geometry metrics.
- Independent afterSRC and pre-SAMURAI deployment generation.
- Legacy external-route isolation.

Both current deployment profiles select square screening chambers: 440 × 440 mm for
afterSRC and 450 × 450 mm for pre-SAMURAI. The former afterSRC cylindrical candidate was
removed by project direction; it is not an active alternative in that deployment profile.

## Schema disposition

Schema version 3 replaces the oversized cassette and procedural cartridge fields with `detector.head` and `sector_holder`.

Removed temperature/housekeeping fields are recursively rejected. They are not accepted as dead configuration and do not produce hidden geometry.

Legacy schema-1 entry-point profiles remain available without a housekeeping block. They are compatibility inputs, not the preferred architecture.

## Validation outcome

The redesigned non-strict FreeCAD validation passes all geometry and engineering-intent checks. Expected warnings remain for unresolved supplier/site/material/pressure-vessel evidence.

The redesigned test intent includes:

- component-complete detector stack;
- SiPM/coupling axial alignment;
- 18 mm housing-depth gate;
- no monitoring geometry or required channels;
- exactly three heads per coherent sector holder;
- no obsolete rails or thermal straps;
- no head/head or holder/holder overlap;
- clear detector-head withdrawal and sampled initial holder release; complete holder extraction is
  deployment-specific and remains unresolved where the current baseline says so;
- no full-acceptance obstruction, including provisional fastener envelopes;
- clear cable/service routes;
- valid solids;
- default role visibility;
- independent deployment generation.

## Unresolved decisions

- Evidence for changing repository `proton_large.angle_deg` from 53.4° toward the previously supplied approximately 55.9° nominal.
- Evidence for changing `proton_small.angle_deg` from 11.2° toward approximately 11.3°.
- PCB/carrier drawing and mounting details.
- Connector, cable exit, and strain-relief selection.
- Reflector and optical-coupling material.
- Final fasteners, tolerances, surface treatment, and survey tooling.
- Chamber closure, tool access, and the complete holder reorientation/lift path.
- Purchased interface drawings, site envelopes, vacuum qualification, and chamber FEA.

The current carrier is a provisional, mechanically defensible concept. It is not a fabrication release.

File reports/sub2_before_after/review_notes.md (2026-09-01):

# Sub-2 Visual Review Notes

> **ARCHIVED HISTORICAL REVIEW (2026-04-24).** The FCStd paths and commands below refer to the former
> root layout of the external H+V+V models. This evidence is not a review of either current
> CompactInVacuum baseline instrument; use `codex_targets.yaml` for current locations.

- **Reviewed FCStd**: `afterSRC/afterSRC.FCStd`, `infrontofSamuraiMag/infrontofSamuraiMag.FCStd`
- **Reviewer**: automated (artifact + Document.xml inventory); pending human GUI sign-off
- **Date**: 2026-04-24
- **Plan**: `docs/superpowers/plans/2026-04-17-detector-clamp-weldment-redesign.md` Task 14
- **Git head at export**: `90a1e35`

## Scope

Review the geometry change introduced by Tasks 1–12 of the detector-clamp weldment redesign plan — the primitive-soup fixture per detector position is replaced by three explicit PartDesign-equivalent bodies (Weldment_LoadBearing, UpperClamp_Detachable, BasePlate_Bolted) plus discrete fastener hardware, with chamfers and fillets on exposed edges.

## Inventory (Document.xml, post-rebuild)

| Module | Total Part::Feature objects |
| --- | --- |
| afterSRC | 330 |
| infrontofSamuraiMag | 324 |

### afterSRC detector-fixture counts

| Family | Count | Per-position |
| --- | --- | --- |
| `Weldment_LoadBearing_<sector>_<channel>` | 12 | 1 × 12 positions |
| `UpperClamp_Detachable_<sector>_<channel>` | 12 | 1 × 12 positions |
| `BasePlate_Bolted_<sector>_<channel>` | 12 | 1 × 12 positions |
| `DetectorFastener_…_clamp_bolt_M6_*` | 48 | 4 × 12 positions |
| `DetectorFastener_…_plate_side_bolt_M8_*` | 48 | 4 × 12 positions |
| `DetectorFastener_…_plate_side_washer_M8_*` | 48 | 4 × 12 positions |
| `DetectorFastener_…_weldment_side_nut_M8_*` | 48 | 4 × 12 positions |
| `DetectorHousing_<sector>_<channel>` | 12 | 1 × 12 positions |

Positions = 4 sectors (`left`, `right`, `up`, `down`) × 3 channels (`deuteron`, `proton_large`, `proton_small`) = 12; matches BLP v1 baseline.

Per-position bolt/nut/washer arithmetic: 4 clamp bolts (M6, top-down into clamp-to-weldment flange) + 4 plate-side stacks (M8 bolt + washer → through BasePlate → captive nut welded to weldment) = 4 + 4×3 = 16 fastener objects. × 12 positions = 192, matches Document.xml count.

### infrontofSamuraiMag deltas

Same detector-fixture family counts (324 total vs. 330 is explained by the different vacuum interface hardware: VF100 + VG80 + 4 side ports instead of afterSRC's ICF114 + ICF70).

## Confirmed against spec

- [x] 12 detector positions with identical `Weldment + UpperClamp + BasePlate` triplets (per-position names derived from `{sector}_{channel}`).
- [x] Fastener set per position is 16 objects (4 clamp + 4 plate bolt + 4 plate washer + 4 weldment nut). No stray fasteners, no missing ones.
- [x] Fastener thread-diameter mapping holds: clamp bolts `M6`, plate stack `M8`. (Document.xml names carry suffix `_M6_*` / `_M8_*`.)
- [x] Validation report `detector_fixture_no_interpenetration` checks present and pass for all 12 positions, strict=true, in both modules (see `afterSRC.validation_report.json`, `infrontofSamuraiMag.validation_report.json`).
- [x] STEP export enumerates 96,142 entities (afterSRC), confirming the solid bodies were flattened correctly for downstream CAD.
- [x] Pipeline runs under `IFSM_SKIP_FCSTD_ROUNDTRIP=1` with strict validation passing; both modules force-rebuilt cleanly from target.yaml.
- [x] Pytest suite: 40 passed, 33 skipped (skipped = FreeCAD-runtime-only tests).

## Pending items (need GUI review)

These require opening the FCStd in the FreeCAD GUI and visually inspecting — they cannot be verified from Document.xml alone:

- [ ] Visible chamfers on external edges of `Weldment_LoadBearing` (width ≈ `chamfer_mm` from config).
- [ ] Fillets at saddle↔ring, adapter↔saddle, upright↔bridge transitions.
- [ ] Hex-socket bolt heads actually rendered as hex geometry (not placeholder) at clamp-bolt and plate-bolt positions.
- [ ] Washers + nuts visible and co-located with plate-side/weldment-side bolt shafts.
- [ ] Oblique channels at `proton_large` (53.4°) positions — no visible clash between clamp halves, fasteners, and detector housing.
- [ ] Feature tree: 3 bodies per position with Pad/Hole/Fillet/Chamfer features (or Path-B `Part::Feature` wrappers — either is acceptable per Task 10 outcome).

## Screenshot capture (deferred)

The plan's before/after PNGs (`before_afterSRC.png`, `after_afterSRC.png`, `before_ifsm.png`, `after_ifsm.png`) are not produced here. Reasons:

1. FCStd files are gitignored, so "before" cannot be recovered by `git checkout -- *.FCStd`; would need a full checkout to pre-Task-10 code + rebuild (~10 min × 2 modules).
2. `IFSM_SKIP_FCSTD_ROUNDTRIP=1` means the exported FCStds have no `GuiDocument.xml`; opening in GUI will show default visibility + camera (fine for review, but camera framing must be set manually per position).
3. Offscreen Coin3D rendering at 330 viewprovider scale deadlocks in futex (FreeCAD #22870 class bug), so automation via `freecadcmd` + SoOffscreenRenderer is not viable at this scale.

Capture instructions for human reviewer (with FreeCAD GUI + MCP RPC server running):

```
# After — current head
FreeCAD GUI: open afterSRC/afterSRC.FCStd, zoom to one detector fixture at 20.9° (down_deuteron),
  screenshot → reports/sub2_before_after/after_afterSRC.png
Same for infrontofSamuraiMag/infrontofSamuraiMag.FCStd → after_ifsm.png

# Before — pre-Task-10 reconstruction
git log --oneline -- infrontofSamuraiMag/src/ifsm/components.py | find commit before Task 10 (object count 132)
git worktree add /tmp/sub2-before <commit-before-task-10>
cd /tmp/sub2-before && IFSM_SKIP_FCSTD_ROUNDTRIP=1 ./afterSRC/run_afterSRC.sh --force-rebuild
Open the resulting FCStd, same camera framing → before_afterSRC.png / before_ifsm.png
git worktree remove /tmp/sub2-before
```

## Open Items / Nits

- None identified from static inventory. Human GUI review may add cosmetic notes.

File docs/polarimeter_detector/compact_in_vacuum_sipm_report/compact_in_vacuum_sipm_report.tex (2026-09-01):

\documentclass[10pt,letterpaper]{article}

\usepackage{fontspec}
\setmainfont{TeX Gyre Termes}
\setsansfont{TeX Gyre Heros}
\setmonofont{DejaVu Sans Mono}[Scale=0.82]

\usepackage[margin=0.82in,headheight=15pt]{geometry}
\usepackage{microtype}
\usepackage{amsmath}
\usepackage{amssymb}
\usepackage{booktabs}
\usepackage{array}
\usepackage{tabularx}
\usepackage{longtable}
\usepackage{adjustbox}
\usepackage{enumitem}
\usepackage{graphicx}
\usepackage{xcolor}
\usepackage[most]{tcolorbox}
\usepackage{titlesec}
\usepackage{fancyhdr}
\usepackage{siunitx}
\usepackage{pgfplots}
\usepackage[american]{circuitikz}
\usepackage{fancyvrb}
\usepackage{csquotes}
\usepackage[
  backend=biber,
  style=numeric,
  sorting=none,
  maxbibnames=9,
  url=true,
  doi=true
]{biblatex}
\usepackage[
  colorlinks=true,
  linkcolor=blue!45!black,
  citecolor=blue!45!black,
  urlcolor=blue!55!black,
  pdfauthor={CompactInVacuum Polarimeter Project},
  pdftitle={CompactInVacuum Common Detector Platform for the afterSRC and pre-SAMURAI Polarimeters}
]{hyperref}
\usepackage{bookmark}
\usepackage[nameinlink,noabbrev]{cleveref}

\addbibresource{references.bib}
\pgfplotsset{compat=1.18}
\sisetup{
  detect-all,
  group-separator={,},
  group-minimum-digits=4,
  range-phrase={--},
  range-units=single
}

\definecolor{ReportBlue}{HTML}{2E74B5}
\definecolor{ReportDarkBlue}{HTML}{1F4D78}
\definecolor{ReportText}{HTML}{202124}
\definecolor{ReportMuted}{HTML}{5F6368}
\definecolor{ReportGreen}{HTML}{E8F3EC}
\definecolor{ReportAmber}{HTML}{FFF4D6}
\definecolor{ReportRed}{HTML}{FCE8E6}
\definecolor{ReportLight}{HTML}{F2F4F7}

\titleformat{\section}
  {\sffamily\bfseries\Large\color{ReportBlue}}
  {\thesection.}{0.55em}{}
\titleformat{\subsection}
  {\sffamily\bfseries\large\color{ReportBlue}}
  {\thesubsection}{0.55em}{}
\titleformat{\subsubsection}
  {\sffamily\bfseries\normalsize\color{ReportDarkBlue}}
  {\thesubsubsection}{0.55em}{}
\titlespacing*{\section}{0pt}{1.6em}{0.7em}
\titlespacing*{\subsection}{0pt}{1.25em}{0.45em}
\titlespacing*{\subsubsection}{0pt}{1.0em}{0.35em}

\setlength{\parindent}{0pt}
\setlength{\parskip}{0.55em}
\setlength{\tabcolsep}{4pt}
\renewcommand{\arraystretch}{1.18}
\setlist[itemize]{leftmargin=1.35em,itemsep=0.25em,topsep=0.25em}
\setlist[enumerate]{leftmargin=1.55em,itemsep=0.3em,topsep=0.3em}

\pagestyle{fancy}
\fancyhf{}
\fancyhead[L]{\sffamily\scriptsize COMPACTINVACUUM COMMON PLATFORM}
\fancyhead[R]{\sffamily\scriptsize PRELIMINARY ENGINEERING REPORT}
\fancyfoot[L]{\sffamily\scriptsize Not for fabrication or purchase-order release}
\fancyfoot[R]{\sffamily\scriptsize Page \thepage}
\renewcommand{\headrulewidth}{0.25pt}
\renewcommand{\footrulewidth}{0pt}

\newcolumntype{Y}{>{\raggedright\arraybackslash}X}
\newcolumntype{C}[1]{>{\centering\arraybackslash}p{#1}}
\newcolumntype{L}[1]{>{\raggedright\arraybackslash}p{#1}}

\newtcolorbox{decisionbox}[1]{
  enhanced,
  breakable,
  colback=ReportGreen,
  colframe=ReportBlue!45,
  boxrule=0.55pt,
  arc=1.2mm,
  left=2.2mm,
  right=2.2mm,
  top=1.8mm,
  bottom=1.8mm,
  title={#1},
  fonttitle=\sffamily\bfseries,
  coltitle=ReportDarkBlue
}

\newtcolorbox{warningbox}[1]{
  enhanced,
  breakable,
  colback=ReportRed,
  colframe=red!45!black,
  boxrule=0.55pt,
  arc=1.2mm,
  left=2.2mm,
  right=2.2mm,
  top=1.8mm,
  bottom=1.8mm,
  title={#1},
  fonttitle=\sffamily\bfseries,
  coltitle=red!45!black
}

\newtcolorbox{notebox}[1]{
  enhanced,
  breakable,
  colback=ReportAmber,
  colframe=orange!55!black,
  boxrule=0.5pt,
  arc=1.2mm,
  left=2.2mm,
  right=2.2mm,
  top=1.6mm,
  bottom=1.6mm,
  title={#1},
  fonttitle=\sffamily\bfseries,
  coltitle=orange!45!black
}

\newcommand{\datatag}[1]{%
  \par{\sffamily\scriptsize\color{ReportMuted}Data origin: \path{#1}}\par
}
\newcommand{\proposal}{\textsc{Proposed}}
\newcommand{\derived}{\textsc{Derived}}
\newcommand{\sourcevalue}{\textsc{Source}}
\newcommand{\provisional}{\textsc{Provisional}}

\input{generated/macros.tex}

\begin{document}
\hypersetup{pageanchor=false}

\begin{titlepage}
  \thispagestyle{empty}
  \vspace*{0.62in}

  {\sffamily\bfseries\fontsize{25}{29}\selectfont\color{ReportText}
  CompactInVacuum Common\par
  Detector Platform\par}
  \vspace{0.25em}
  {\sffamily\fontsize{14}{18}\selectfont\color{ReportMuted}
  Engineering Report for the afterSRC and pre-SAMURAI In-Vacuum Polarimeters\par}
  \vspace{0.12em}
  {\sffamily\fontsize{11}{14}\selectfont\color{ReportMuted}
  SiPM detector, vacuum integration, and China-sourcing study\par}

  \vspace{0.55in}
  \renewcommand{\arraystretch}{1.35}
  \begin{tabularx}{\textwidth}{>{\sffamily\bfseries}L{0.23\textwidth}Y}
    \toprule
    Status & Canonical afterSRC ICF305-access and common-detector preliminary study \\
    Issue date & 1 September 2026 \\
    CAD reference & Polarimeter commit \texttt{\ReportGitCommit} \\
    Architecture authority & \path{docs/specs/compact_one_requirement_baseline.md} \\
    Deployment profiles & \path{compactInVacuum/config/afterSRC_compact.yaml};
      \path{compactInVacuum/config/infrontSamurai_compact.yaml} \\
    Numerical reference & Canonical afterSRC target, manifest, and resolved validation configuration \\
    Source validation & \SourceValidationStatus; \SourceValidationMode \\
    Procurement region & People's Republic of China preferred \\
    Primary integration candidate & Shanghai PrMat Precision Instrument Technology Co., Ltd. (conditional qualification) \\
    \bottomrule
  \end{tabularx}

  \vfill
  \begin{warningbox}{PROJECT BASELINE -- PRELIMINARY, NOT FOR FABRICATION OR PURCHASE RELEASE}
    Two CompactInVacuum polarimeters are the current baseline: one after SRC and one before
    SAMURAI. Both place their scintillator/SiPM detectors inside vacuum and share a common
    detector platform. The current CAD profiles use separate square screening chambers:
    \SI{440}{\milli\meter} by \SI{440}{\milli\meter} for afterSRC and
    \SI{450}{\milli\meter} by \SI{450}{\milli\meter} for pre-SAMURAI. Their beamline
    interfaces remain site-specific and independently controlled. The old afterSRC
    external-detector concept is retained only as a legacy/fallback/reference route.
  \end{warningbox}

  \vspace{0.22in}
  {\small\color{ReportMuted}
  The numerical tables in this LaTeX report are generated from version-controlled source files.
  The complete reproduction command is \texttt{make verify}; see \cref{sec:verification}.}
\end{titlepage}

\hypersetup{pageanchor=true}
\pagenumbering{roman}
\tableofcontents
\clearpage
\pagenumbering{arabic}

\section{Executive decision}

\begin{decisionbox}{Authoritative two-instrument architecture}
  Two compact in-vacuum polarimeters are planned for the polarized-deuteron experiment.
  \textbf{CompactInVacuum-afterSRC} will be installed downstream of SRC, and
  \textbf{CompactInVacuum-preSAMURAI} will be installed before the SAMURAI terminal.
  Both instruments use a common CompactInVacuum detector-platform concept, while their
  chamber geometry, beamline interfaces, target integration, supports, and maintenance
  access remain site-specific. The previously studied afterSRC external-detector
  configuration is retained as a legacy/reference alternative but is not the present
  baseline. The selected afterSRC screening chamber is square, not cylindrical.
\end{decisionbox}

\begin{decisionbox}{Recommended first-prototype baseline}
  \begin{itemize}
    \item Use a fast blue plastic scintillator, not a high-light-yield inorganic crystal.
    \item Use the canonical \SI{\ActiveDiameterMm}{\milli\meter} diameter by
      \SI{\ActiveThicknessMm}{\milli\meter} active element as the first prototype, while
      retaining \SIrange{5}{6}{\milli\meter} coupons until production thickness is frozen.
    \item Use the NDL EQR15 11-6060D-S as the baseline SiPM. Keep the NDL EQR20 as a
      higher-gain backup and a Hamamatsu S13360-6025CS as an imported reference.
    \item Design and measure the total optical collection into the SiPM active area in the
      2--5\% range. Do not treat this efficiency as a vendor specification.
    \item Keep active electronics outside vacuum. Carry each fast signal through one shielded
      \SI{50}{\ohm} coaxial feedthrough, with SiPM bias supplied through an external bias tee.
  \end{itemize}
\end{decisionbox}

At the \SI{\ActiveThicknessMm}{\milli\meter} candidate's maximum calculated normal elastic
d--p deposit of \SI{\CandidateMaximumDepositMeV}{\mega\electronvolt}, the EQR15 short-pulse microcell
nonlinearity is \EqrNormalNonlinearityTwo\% at 2\% optical collection and
\EqrNormalNonlinearityFive\% at 5\%. At 5\%, the associated primary-avalanche charge is
\SI{\EqrNormalCharge}{\nano\coulomb}. The SiPM is therefore viable, but the front-end can
still clip before the microcells become unacceptable. The first prototype must provide a
timing path, a protected low-gain charge path, and a calibrated light-injection scan.
For comparison, the legacy \SI{\LegacyThicknessMm}{\milli\meter} calculation reaches
\SI{\LegacyMaximumDepositMeV}{\mega\electronvolt}, \EqrLegacyNormalNonlinearityFive\%
nonlinearity, and \SI{\EqrLegacyNormalCharge}{\nano\coulomb} at the same optical efficiency.

The calculated carbon background point is deliberately conservative: it applies the
electron-equivalent reference light yield without Birks quenching. Its EQR15 microcell
nonlinearity is \EqrCarbonNonlinearity\% at 5\% optical collection. Heavy-ion quenching
will reduce the real occupancy, but the correction must be measured rather than assumed.

Shanghai PrMat is a reasonable candidate for vacuum-chamber integration because it publicly
describes custom vacuum-component design and manufacturing capability
\cite{prmat_about,prmat_kcell}. This is candidate evidence, not prequalification. The
purchase route must require a formal RFQ, design-for-manufacture review, weld and inspection
plans, dimensional inspection, cleaning records, and helium-leak acceptance.

\begin{warningbox}{Current afterSRC access selection; beam and service interfaces remain evidence-qualified}
  The old afterSRC external-detector design used ICF114 front/rear beam interfaces and an
  ICF70 rotary mount. These are class B legacy inheritance. The current CompactInVacuum
  reference CAD also contains ICF114/ICF70 envelope assumptions; these are class C engineering
  assumptions. Neither statement is independent class A evidence for CompactInVacuum-afterSRC,
  and the CompactInVacuum-preSAMURAI interface is likewise unresolved.

  The canonical afterSRC prototype now uses a \MaintenanceAccessStandard\ top maintenance
  opening with a \SI{\MaintenanceAccessClearBoreMm}{\milli\meter} screening bore, an OFHC
  copper gasket, and no elastomer/O-ring seal. Its detached-holder passage screen has
  \SI{\MaintenanceAccessPassageMarginMm}{\milli\meter} nominal margin, but the complete
  installed-holder release, reorientation, and lift remains \MaintenanceExtractionStatus.
  The removable blank flange carries no detector, support, locating datum, protective-ground
  termination, or permanent cable restraint. Front/rear beam standards, pumping, gauge,
  isolation-valve, rotary, and signal-feedthrough selections still require approved site and
  purchased-part evidence.
\end{warningbox}

\begin{table}[htbp]
  \centering
  \small
  \caption{Decision summary and release conditions.}
  \begin{tabularx}{\textwidth}{L{0.18\textwidth}Y Y}
    \toprule
    Item & Recommended decision & Release condition \\
    \midrule
    Scintillator & Fast blue plastic; \SIrange{5}{6}{\milli\meter} first-prototype study band &
      Source/beam timing, threshold, light-output, and thickness-comparison data \\
    SiPM & EQR15 baseline; EQR20 backup; Hamamatsu reference &
      Bench linearity, gain, dark rate, temperature coefficient, and lot screening \\
    Chamber & Separate square chambers: \SI{440}{\milli\meter} by
      \SI{440}{\milli\meter} afterSRC with all-metal ICF305 maintenance access, and
      \SI{450}{\milli\meter} by \SI{450}{\milli\meter} pre-SAMURAI & Port map,
      complete extraction motion, external-pressure FEA, handling mass, and access review
      for each deployment \\
    Site interfaces & afterSRC compact and pre-SAMURAI compact defined independently; current
      beam interfaces TBD & Approved beamline drawings, site surveys, selected purchased
      components, vacuum-boundary definition, and leak acceptance \\
    PrMat workshare & Chamber, rotary-feedthrough integration, detector-head and
      sector-holder interfaces, final
      dimensional and leak acceptance & Accepted capability questionnaire and quality plan \\
    Detector workshare & Scintillator supplier plus project electronics team &
      A golden detector head and one complete sector pass optical, vacuum, electrical,
      mechanical-removal, and coincidence tests \\
    \bottomrule
  \end{tabularx}
\end{table}

\section{Scope, reference configuration, and decision state}

This report develops the \emph{common} CompactInVacuum detector platform for both baseline
instruments. It does not define one universal chamber. The existing numerical detector,
energy-loss, saturation, electronics, service, detector-head, sector-holder, mass-screening,
manufacturing, and China-sourcing studies remain useful common-platform work. The current
screening profiles use square chambers at both sites, while their dimensions and interfaces
remain independently controlled rather than copied from the legacy afterSRC chamber.

\begin{center}
\begin{minipage}{0.72\textwidth}
\begin{Verbatim}[fontsize=\small,frame=single]
SRC
 |
 +-- CompactInVacuum-afterSRC
 |
 |   beam transport
 |
 +-- CompactInVacuum-preSAMURAI
 |
SAMURAI

Both:  common detector platform
       site-specific mechanics/interfaces
Legacy: afterSRC external detector
        reference/fallback only
\end{Verbatim}
\end{minipage}
\end{center}

\begin{table}[htbp]
  \centering
  \small
  \caption{Authoritative status of the polarimeter concepts.}
  \begin{tabularx}{\textwidth}{L{0.22\textwidth}Y Y Y}
    \toprule
    Item & afterSRC compact & pre-SAMURAI compact & legacy afterSRC external \\
    \midrule
    Baseline status & Baseline & Baseline & Legacy/fallback \\
    Detector location & In vacuum & In vacuum & Outside vacuum \\
    Detector platform & Common compact platform & Common compact platform & Old external design \\
    Chamber geometry & Square, \SI{440}{\milli\meter} by \SI{440}{\milli\meter},
      provisional & Square, \SI{450}{\milli\meter} by \SI{450}{\milli\meter},
      provisional & Existing reference \\
    Beam interfaces & Verify independently & Verify independently & Existing assumptions \\
    \bottomrule
  \end{tabularx}
\end{table}

\subsection{Requirement separation}

\textbf{Common platform requirements.}
Scintillator and SiPM technology, the explicit compact detector-head stack, coherent
three-head sector holders, twelve signal channels, passive conductive interfaces,
electronics, calibration, and common physics/response studies.

\textbf{afterSRC site requirements.}
Actual longitudinal/transverse envelope, usable beam aperture, neighboring equipment,
flange interfaces, target integration, vacuum services, support/alignment, and
installation/maintenance access downstream of SRC.

\textbf{pre-SAMURAI site requirements.}
The same site categories, established independently for the location before the SAMURAI
terminal.

Unknown site quantities remain TBD. Closure requires an approved interface drawing,
local survey or measurement, neighboring equipment envelope, beam stay-clear, vacuum-service
ownership, support datums, and an installation/maintenance review.

\subsection{Interface evidence classification}

\begin{table}[htbp]
  \centering
  \small
  \caption{Interface claims and the evidence level they currently support.}
  \begin{tabularx}{\textwidth}{L{0.22\textwidth}C{0.10\textwidth}Y Y}
    \toprule
    Item & Class & Current status & Evidence needed to close \\
    \midrule
    CompactInVacuum-afterSRC beam interfaces & D & Front/rear standards and usable bore TBD &
      Approved afterSRC compact mating-interface drawing and site survey \\
    CompactInVacuum-afterSRC rotary interface & C & ICF70 is a provisional study envelope &
      Site requirement, load case, and signed purchased-part/interface drawing \\
    CompactInVacuum-preSAMURAI beam interfaces & D & Mating chain and usable bore TBD &
      Approved pre-SAMURAI mating-chain drawing and site survey \\
    CompactInVacuum-preSAMURAI rotary interface & D & Target/feedthrough interface TBD &
      Target-motion requirements and approved site interface \\
    Compact signal-port layout & C & Required signal capacity is known; flange count,
      standards, and locations are provisional & Selected parts plus routing, access, and
      site-envelope review for each instrument \\
    Legacy afterSRC external interfaces & B & ICF114 front/rear and ICF70 top mount belong
      to the old external design & No propagation to compact afterSRC without independent
      class A evidence \\
    \bottomrule
  \end{tabularx}
\end{table}

Class A means an approved external beamline constraint; B is legacy inheritance; C is a
current engineering assumption; and D is unresolved/TBD. Classes B and C shall not be
described as class A.

The reference physics case is a \SI{\BeamEnergyMeV}{\mega\electronvolt} deuteron beam on a
CH2 target with elastic d--p coincidence in four azimuthal sectors.

\begin{table}[htbp]
  \centering
  \small
  \caption{Detector directions and active-center radii checked against the generated
  channel manifest.}
  \begin{tabular}{L{0.10\textwidth}L{0.13\textwidth}C{0.12\textwidth}C{0.20\textwidth}L{0.24\textwidth}}
    \toprule
    Station & Particle & Angle (\si{\degree}) & Active-center radius (\si{\milli\meter}) &
      Lab acceptance (\si{\degree}) \\
    \midrule
    \input{generated/geometry_table.tex}
  \end{tabular}
  \datatag{generated/geometry_table.tex; generated/provenance.json}
\end{table}

The schema-3 detector configuration now defines a \SI{20}{\milli\meter}-diameter,
\SI{5.5}{\milli\meter}-thick fast-plastic prototype with an NDL EQR15 11-6060D-S-class
SiPM. Its calculated physical head depth is \SI{9.70}{\milli\meter}, measured from the
active entrance face to the rear housing and excluding the cable exit, connector keepout,
and removal envelope. Supplier drawings, reflector material, optical-pad material, PCB,
connector, and production tolerances remain provisional.

\subsection{Square chamber baseline and current mass screen}

The selected CompactInVacuum-afterSRC screening chamber is square with a provisional
\SI{\ChamberInnerXmm}{\milli\meter} by \SI{\ChamberInnerYmm}{\milli\meter} internal section,
\SI{\ChamberBodyLengthMm}{\milli\meter} body length, and
\SI{\ChamberWallThicknessMm}{\milli\meter} wall. The selected
pre-SAMURAI screening chamber is independently defined as
\SI{450}{\milli\meter} by \SI{450}{\milli\meter}, \SI{380}{\milli\meter} long, with a
provisional \SI{8}{\milli\meter} wall. Neither wall is released without external-pressure,
penetration, weld, support, and handling analysis.

\begin{table}[htbp]
  \centering
  \small
  \caption{Current afterSRC closed-square-shell mass screen. It ignores ports, weld
  preparations, local reinforcements, and removed material and is not a structural release.}
  \begin{tabularx}{\textwidth}{L{0.26\textwidth}L{0.23\textwidth}Y}
    \toprule
    Parameter & Current model / calculation & Engineering interpretation \\
    \midrule
    Inner cross-section & \SI{\ChamberInnerXmm}{\milli\meter} by
      \SI{\ChamberInnerYmm}{\milli\meter} &
      Larger than the internal detector sectors require; drives transport volume \\
    Nominal wall thickness & \SI{\ChamberWallThicknessMm}{\milli\meter} provisional &
      Not releasable without external-pressure buckling analysis and weld details \\
    Body length & \SI{\ChamberBodyLengthMm}{\milli\meter} &
      Active ICF305 integration envelope; the former 360 mm body belongs to the rejected
      ICF253 comparison \\
    Closed-shell material volume & \SI{\ChamberMaterialVolumeL}{\liter} &
      Arithmetic screening value before subtracting ports \\
    Stainless screening mass & \SI{\ChamberScreeningMassKg}{\kilogram} &
      Screening value for handling and support planning, not an as-built mass \\
    Detector count & 12 operating channels &
      Three stations in each of four sectors; purchase plan must include spares \\
    \bottomrule
  \end{tabularx}
  \datatag{compactInVacuum/artifacts/afterSRC/CompactOne_afterSRC.validation_report.json;
  generated/derived_results.json}
\end{table}

\subsection{Current integration direction}

\begin{itemize}
  \item Retain the canonical channel angles, active-center radii, and
    \SI{\ActiveDiameterMm}{\milli\meter} active diameter until physics evidence supports a
    controlled geometry change.
  \item Use a square chamber with planar service walls for both current deployment profiles.
    CompactInVacuum-afterSRC uses the \SI{440}{\milli\meter} square screening profile; a
    cylindrical afterSRC candidate is not retained.
  \item Use the all-metal top ICF305 blank-flange opening for afterSRC maintenance. Keep every
    detector support and locating datum on stationary structure attached to permanent chamber
    walls; do not mount a holder or support on the removable closure.
  \item Treat the validated 12 mm holder release as only the first motion stage. Validate the
    complete translation, reorientation, and lift path separately in the installed STEP model.
  \item Validate each square chamber for external-pressure buckling and local penetration
    loads; the selected shape does not waive pressure-vessel engineering.
  \item Use removable beamline spools, knife-edge covers, lifting points, and a stated
    maximum manually handled subassembly mass.
\end{itemize}

\begin{notebox}{Provisional inputs that still require closure}
  Beam energy and d--p reaction are source-controlled. The \SIrange{5}{6}{\milli\meter}
  prototype thickness band, 2--5\% total optical collection,
  \SI{10000}{photons/MeV} electron-equivalent light yield, populated-detector bake regime,
  and rotary-feedthrough load case remain engineering assumptions. Beam flanges, usable
  apertures, rotary-feedthrough interfaces, vacuum class, operating pressure, and gas-load
  budget remain site-specific and require the responsible beamline owner's evidence.
\end{notebox}

\section{Detector physics and active thickness}

The elastic coincidence acceptance is recalculated from the canonical detector diameter,
active-center radii, and laboratory angles. The forward and backward common center-of-mass
windows are \ForwardCmLow--\ForwardCmHigh\si{\degree} and
\BackwardCmLow--\BackwardCmHigh\si{\degree}, respectively. Energy deposition is then
calculated with the repository's relativistic two-body kinematics and C8H8 range tables.
The primary values use \LisePrimaryRangeModel; the complete CSV includes five LISE++ range
models so interpolation-model spread is visible.

\begin{table}[htbp]
  \centering
  \scriptsize
  \caption{Calculated energy deposition in a \SI{\ActiveThicknessMm}{\milli\meter}
  C8H8 active layer. Carbon values are energy deposits, not electron-equivalent light output.}
  \begin{tabular}{L{0.22\textwidth}C{0.08\textwidth}C{0.17\textwidth}C{0.20\textwidth}L{0.17\textwidth}}
    \toprule
    Reaction / particle & Station & Lab range (\si{\degree}) &
      Deposit in \SI{\ActiveThicknessMm}{\milli\meter} plastic
      (\si{\mega\electronvolt}) & Trace status \\
    \midrule
    \input{generated/energy_table.tex}
  \end{tabular}
  \datatag{generated/energy_deposition.csv; code/data/energy_lise/dp_dc_kinematics.py}
\end{table}

\subsection{Active-thickness recommendation}

The detector acts as a $\Delta E$ counter, not a stopping calorimeter. Accepted d--p
particles have calculated ranges up to approximately \SI{\WorstCaseNormalRangeMm}{\milli\meter};
none of the scanned \SIrange{1}{10}{\milli\meter} options stops every branch. Thickness must
therefore be chosen from timing/threshold margin, optical uniformity, saturation, mechanics,
and coincidence separation rather than from a false full-stopping criterion.

\begin{table}[htbp]
  \centering
  \scriptsize
  \caption{LISE++ thickness scan. Each cell gives the deposited-energy range in
  \si{\mega\electronvolt} for the accepted coincidence branch using
  \LisePrimaryRangeModel. The accompanying generated CSV preserves the full five-model result.}
  \begin{tabular}{C{0.08\textwidth}C{0.16\textwidth}C{0.16\textwidth}
                  C{0.16\textwidth}C{0.16\textwidth}L{0.10\textwidth}}
    \toprule
    Thickness (\si{\milli\meter}) & Forward d & Forward p &
      Backward d & Backward p & Role \\
    \midrule
    \input{generated/thickness_table.tex}
  \end{tabular}
  \datatag{generated/thickness_summary.csv; generated/thickness_scan.csv;
  code/data/energy_lise/lise_range.py}
\end{table}

The \SI{\ActiveThicknessMm}{\milli\meter} candidate gives
\SIrange{\CandidateMinimumDepositMeV}{\CandidateMaximumDepositMeV}{\mega\electronvolt}
over the normal accepted branches and reduces the maximum deposited energy by approximately
\MaximumDepositReductionPercent\% relative to \SI{\LegacyThicknessMm}{\milli\meter}.
It is the compactness/low-saturation starting point, not a frozen optimum. Build at least
\SI{5}{\milli\meter} and \SI{6}{\milli\meter} otherwise-identical detector heads; retain
\SI{4}{\milli\meter}, \SI{8}{\milli\meter}, and \SI{10}{\milli\meter} coupons for threshold,
timing, quenching, and dynamic-range comparison. Freeze production thickness only after a
source or beam test and a version-controlled Geant4 response study.

\subsection{Light-yield quenching}

The saturation model deliberately uses the electron-equivalent light yield as an upper bound.
For heavy charged particles, Birks' law gives the first-order relation
\begin{equation}
  \frac{\mathrm{d}L}{\mathrm{d}x}
  =
  S\,\frac{\mathrm{d}E/\mathrm{d}x}
  {1 + k_B\,\mathrm{d}E/\mathrm{d}x}.
\end{equation}
The supplier batch and the final surface treatment can change the effective light collection,
while the Birks constant depends on material and measurement conditions. No assumed Birks
constant is applied in the saturation numbers. Carbon values are therefore intentionally
conservative for SiPM occupancy but still valuable for defining the calibration range.

\section{Scintillator and compact detector head}

\subsection{Material choice}

\begin{table}[htbp]
  \centering
  \small
  \caption{Qualitative scintillator trade study for the first compact detector.}
  \begin{tabularx}{\textwidth}{L{0.15\textwidth}Y Y L{0.17\textwidth}}
    \toprule
    Material & Main advantage & Main concern & Disposition \\
    \midrule
    Fast blue plastic & Fast coincidence timing; easy machining; low cost; domestic supply route &
      Lower energy resolution; batch and surface quality must be measured & Baseline \\
    CsI(Tl) & High light output and widespread availability &
      Slow decay, hygroscopic handling, severe SiPM saturation risk & Not recommended \\
    GAGG(Ce) & High light output; non-hygroscopic &
      Dense high-Z material, slower timing, higher cost, more saturation & Future comparison only \\
    LYSO(Ce) & Fast inorganic option; high stopping power &
      High cost, high-Z background, intrinsic activity, saturation risk & Not recommended \\
    \bottomrule
  \end{tabularx}
\end{table}
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

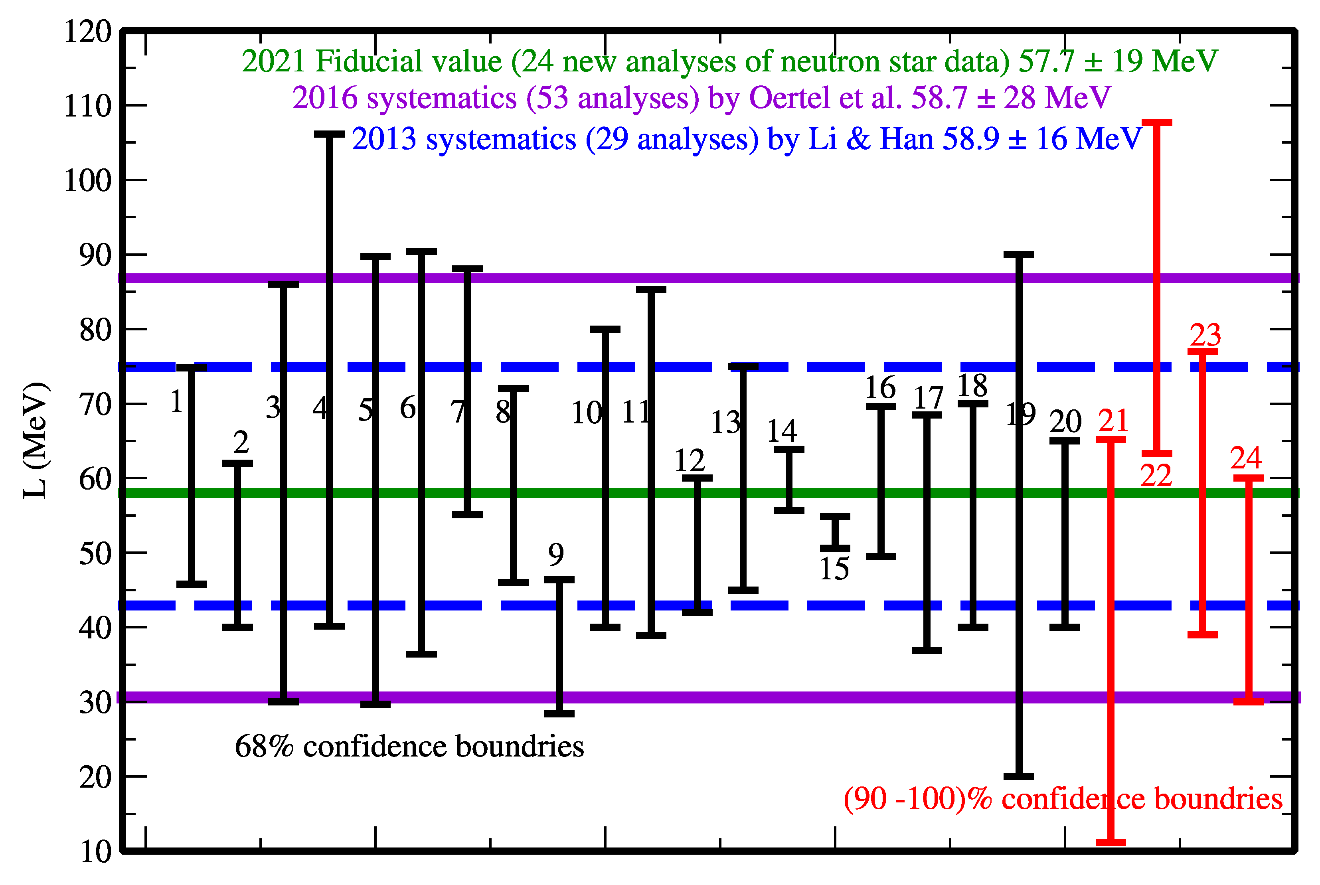
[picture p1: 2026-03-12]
docs/papers/isovector_reorientation/tbt_img/universe2021_Li_SlopeL.png

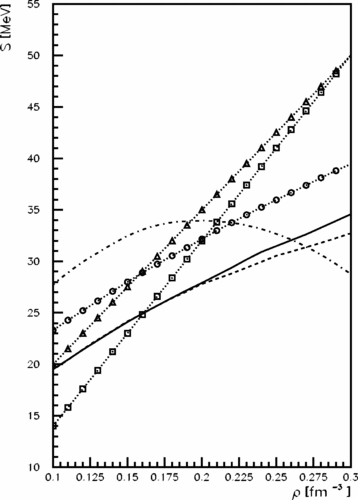
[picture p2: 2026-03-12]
docs/papers/isovector_reorientation/tbt_img/ESymRhoEft.png

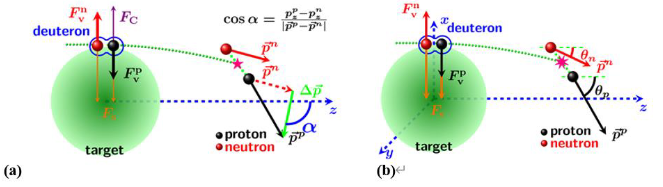
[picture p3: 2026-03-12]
docs/papers/isovector_reorientation/isovectorReorientation.png

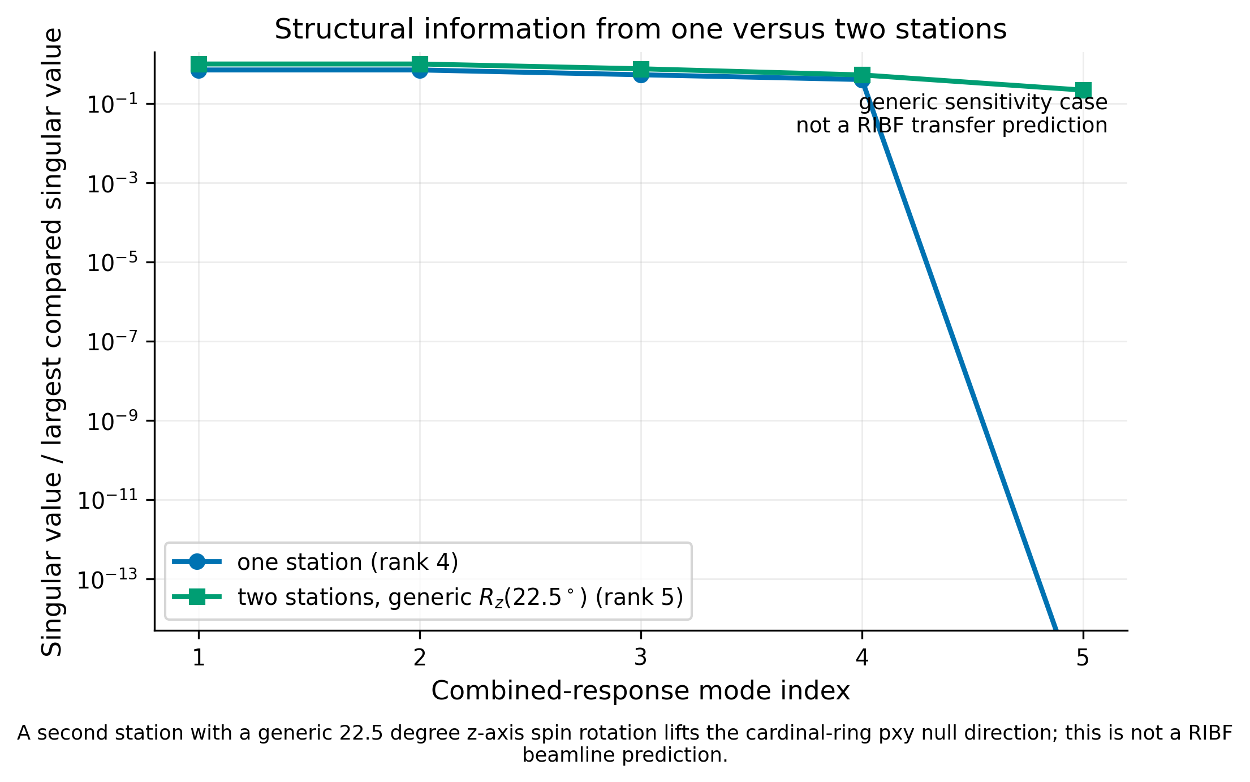
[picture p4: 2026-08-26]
docs/physics/tensor_identifiability/figures/05_one_vs_two_station_singular_spectrum.png

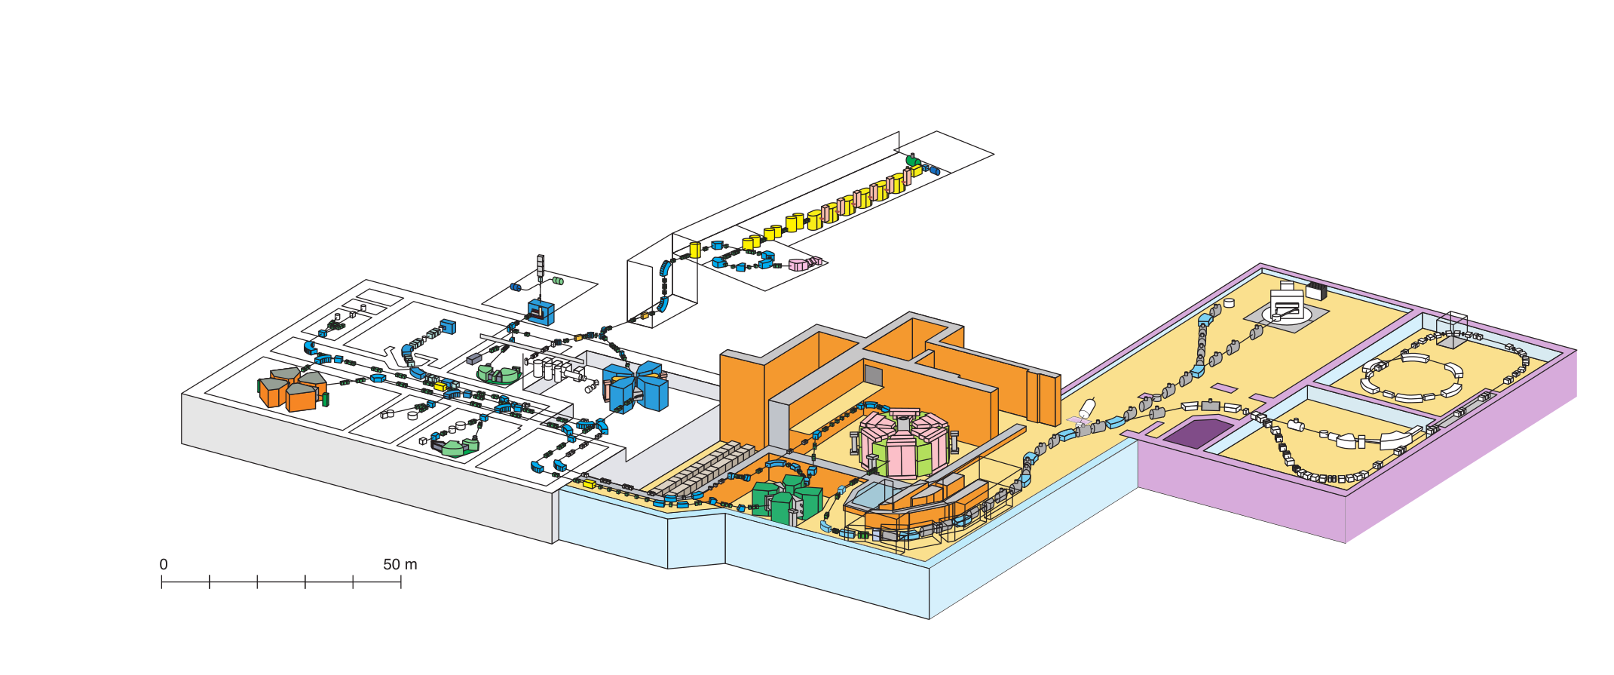
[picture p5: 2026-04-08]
docs/beamline_info/afterSRC/assets/afSRC_overview/image.png

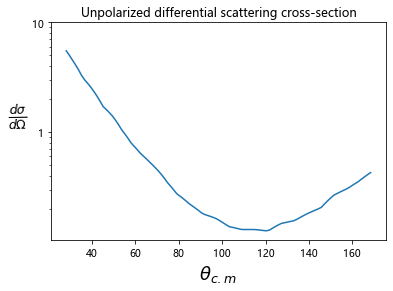
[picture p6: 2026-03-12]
docs/papers/isovector_reorientation/tbt_img/unpolarized_CrossSection.png

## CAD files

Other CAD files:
msu-tpc/Target_mechanism_Jan_30_2018.stp
msu-tpc/Target_mechanism_platform/face_piece.stp
msu-tpc/Tgt_ladder/Ladder_base.stp
msu-tpc/Target_mechanism_platform/fastening_block_2.stp
msu-tpc/Tgt_ladder.stp
msu-tpc/Tgt_ladder/position_holder.stp
msu-tpc/Target_mechanism_platform.stp
msu-tpc/Target_mechanism_platform/top_platform_base.stp
msu-tpc/Target_mechanism_platform/fastening_block.stp
msu-tpc/Tgt_ladder/unique_screw_tgt_ladder.stp
old-version/scintilator/detector_one.SLDASM
old-version/靶框系统.SLDASM
old-version/target&chamber.SLDASM
old-version/all2.SLDASM
old-version/scintilator/base_pmt.SLDPRT
old-version/靶子夹子.SLDPRT
old-version/三块板子.SLDPRT
old-version/scintilator/jiazi.SLDPRT
msu-tpc/Target_mechanism_platform/face_piece.dwg
msu-tpc/Target_mechanism_platform/fastening_block.dwg
msu-tpc/Target_mechanism_platform/fastening_block_2.dwg
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

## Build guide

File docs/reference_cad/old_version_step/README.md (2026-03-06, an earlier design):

# old-version SolidWorks -> STEP Reference Pack

This directory stores neutral CAD exports (`.step`) converted from `old-version/*.SLDPRT` and `old-version/*.SLDASM`.

## 1) Export rule (outside this repo)

Use a SolidWorks-capable machine and export each source file as:

- Format: `STEP AP242`
- Units: `mm`
- Scale: `1.0` (no scaling)
- Naming: keep original base name and relative structure

Examples:

- `old-version/chamber_base.SLDPRT` -> `docs/reference_cad/old_version_step/chamber_base.step`
- `old-version/scintilator/base_pmt.SLDPRT` -> `docs/reference_cad/old_version_step/scintilator/base_pmt.step`

## 2) Build/refresh manifest

From repo root:

```bash
python3 scripts/cad_reference/build_old_version_step_manifest.py
```

Output:

- `docs/reference_cad/old_version_step_manifest.json`

## 3) Validate STEP import in FreeCAD runtime

From repo root:

```bash
./scripts/cad_reference/run_old_version_step_import_check.sh \
  --manifest docs/reference_cad/old_version_step_manifest.json \
  --output docs/reference_cad/old_version_step_import_report.json \
  --strict
```

Output:

- `docs/reference_cad/old_version_step_import_report.json`

## 4) Status files

- Human-updated source: `old-version/*.SLDPRT`, `old-version/*.SLDASM`
- Machine-generated status:
  - `docs/reference_cad/old_version_step_manifest.json`
  - `docs/reference_cad/old_version_step_import_report.json`

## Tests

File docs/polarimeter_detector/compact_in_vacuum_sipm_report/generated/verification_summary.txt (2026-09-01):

CompactInVacuum common-platform report numerical verification
OVERALL: PASS
Git commit: cb57cdf88ebb66067e5f42d8f10175e0d6fe3afd
Source validation status: pass
Source validation mode: prototype_non_strict (strict=False)
CAD detector decision state: active_medium=fast_blue_plastic (selected), photosensor=NDL EQR15 11-6060D-S (selected)
Canonical detector prototype: fast blue plastic scintillator + NDL EQR15 11-6060D-S
Thickness study: primary=atima_1_2_ls, candidate=5.5 mm, candidate deposit=1.8778-15.1492 MeV, legacy maximum=35.9826 MeV
Project baseline: CompactInVacuum-afterSRC + CompactInVacuum-preSAMURAI; legacy afterSRC external=reference/fallback
Compact beam interfaces: afterSRC=D/TBD; preSAMURAI=D/TBD; current provisional CAD envelope=ICF114/ICF114
afterSRC maintenance access: ICF305, metal seal, passage screen margin=23.761 mm, complete extraction=placeholder

Checks:
PASS | CAD validation pass | validation status=pass
PASS | Target/validation mode agreement | target.strict=False, artifact.strict=False
PASS | Target artifact paths match report inputs | manifest=compactInVacuum/artifacts/afterSRC/CompactOne_afterSRC.channel_manifest.json, report=compactInVacuum/artifacts/afterSRC/CompactOne_afterSRC.validation_report.json
PASS | deuteron geometry source agreement | delta_angle=0 deg, delta_radius=0 mm
PASS | proton_small geometry source agreement | delta_angle=0 deg, delta_radius=0 mm
PASS | proton_large geometry source agreement | delta_angle=0 deg, delta_radius=0 mm
PASS | Report thickness matches canonical CAD active thickness | report=5.500 mm, CAD=5.500 mm
PASS | Candidate thickness agrees with the detailed energy table | computed=15.1492 MeV
PASS | Carbon energy remains below the conservative report bound | computed=192.0522 MeV, upper_bound=192.8 MeV
PASS | Candidate minimum normal d-p deposit | minimum=1.8778 MeV, threshold=1.5000 MeV
PASS | Candidate is treated as a delta-E counter rather than a stopping calorimeter | thickness=5.5 mm, maximum accepted-particle range=594.79 mm
PASS | Candidate reduces the maximum normal deposit relative to 10 mm | candidate=15.1492 MeV, legacy=35.9826 MeV
PASS | EQR15 candidate-thickness nonlinearity at 5 percent collection | computed=1.0104%, limit=2.0000%
PASS | EQR15 conservative carbon nonlinearity | computed=11.8949%
PASS | Beam transition pipe has a positive radial wall | outer=63.500 mm, inner=60.200 mm, radial_wall=1.650 mm
PASS | Beam transition bore matches the resolved vessel bore | pipe_inner=60.200 mm, vessel_bore=60.200 mm
PASS | Two CompactInVacuum baseline instruments are declared | CompactInVacuum-afterSRC=baseline, CompactInVacuum-preSAMURAI=baseline
PASS | External afterSRC design is legacy/fallback/reference | status=legacy/fallback/reference, interface_class=B
PASS | Compact deployment beam interfaces remain independently unresolved | afterSRC=D/TBD; preSAMURAI=D/TBD
PASS | Provisional CAD beam interfaces remain labelled as reference envelopes | reference CAD front=ICF114, rear=ICF114; not a compact deployment contract
PASS | Reference ICF114 bore does not reduce the resolved transition bore | resolved transition bore=60.200 mm, reference clear bore=60.200 mm; site-interface approval remains independent
PASS | afterSRC maintenance opening is the all-metal ICF305 prototype | standard=ICF305, seal=oxygen_free_copper, elastomer_allowed=False
PASS | Complete holder extraction remains explicitly unresolved | status=placeholder
PASS | ICF-class assembly helium-leak target | acceptance<=1.000e-10 Pa m^3/s

Reproduction command:
micromamba run -n anaroot-env python scripts/generate_report_data.py --check

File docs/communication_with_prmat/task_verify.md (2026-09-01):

您好：

文档状态：2026-09-01 工程对接草案，仅用于能力确认和可制造性评审，不可直接用于加工、采购或压力容器放行。

我正在设计两套用于氘束偏振测量的真空内紧凑型偏振仪，希望咨询贵公司是否能够参与其机械设计、加工、探测器安装集成及真空验收。

目前项目处于初步工程设计和供应商能力确认阶段，现有三维模型主要用于技术讨论，尚不是最终加工图纸。

一、系统概况

我们计划建设两套独立的真空内偏振仪：

1.  一套安装在SRC下游；当前STEP中前后ICF114仅为由旧方案继承的布置包络，尚不是已批准的束线接口合同；
2.  一套安装在SAMURAI磁铁前，其束流线接口和安装空间需要按照现场条件独立设计, 这个真空要求会低很多，不能直接复制第一套设备。

两套设备使用相同的探测器原理，但真空腔体尺寸、束流接口、支撑结构和检修空间可能不同。

每套设备包含四个方位，每个方位安装三个塑料闪烁体–SiPM探测器通道，因此每套共12个探测器模块，两套共24个。

初步探测器方案为：

* 快塑料闪烁体，有效直径约20 mm，厚度约5–6 mm；
* 约6 mm × 6 mm的SiPM，例如NDL EQR15 11-6060D-S；
* 探测器和SiPM位于真空内；
* 每个探测器使用独立50 Ω同轴线引出信号和偏压；
* 放大器、bias tee及数字化电子学位于真空外；
* 探测器模块要求遮光、可拆卸、后方出线，并具有明确的安装基准和应力释放结构。

二、希望贵公司评估的工作范围

希望了解贵公司是否能够承担以下工作：

1. 两套真空腔体的详细机械设计、加工及焊接；
2. 标准真空法兰、过渡管、服务端口和真空馈通的选型与集成；
3. 四个可拆卸探测器sector及每个sector内三个探测器模块的安装支架；
4. 探测器模块的定位基准、拆装结构、真空内走线和应力释放设计；
5. CH₂靶框、旋转轴、真空旋转馈通、工作位及退出位机构；
6. afterSRC 腔体顶面暂推荐采用标准圆形 ICF305/CF 全金属检修口和盲板，使用无氧铜垫片，不使用 O 形圈或其他弹性体密封。请评估固定法兰、焊颈、加强区和盲板的可制造性；检修盲板不承载探测器、定位销、结构支撑、保护接地端或永久线缆固定件；
7. 请结合泵组和规管选型，评估腔体独立抽气口、真空规管口、抽气隔离阀，以及束流上下游全通径真空插板阀/闸阀的法兰尺寸和布置；
8. 整机支撑、安装和对准结构；
9. 真空清洗、总装、尺寸检测及氦检漏；
10. STEP图纸、加工图、材料清单、尺寸检测报告和检漏报告的交付。

三、关于探测器模块的合作方式

我们希望同时了解贵公司是否具备以下能力：

1. 采购或代购指定型号的塑料闪烁体和SiPM；
2. 完成塑闪加工、光学耦合、SiPM载板、遮光封装和同轴线连接；
3. 对完成的探测器模块进行暗电流、击穿电压、光响应、密封遮光和真空环境测试；
4. 或者由我方提供完整的探测器模块，贵公司只负责机械盒体、sector支架、真空腔体和最终集成。

如贵公司不负责探测器光学和电子学部分，也请说明建议由我方提供到何种状态，例如裸塑闪和SiPM、已经封装的探测器模块，或者带同轴线的完整模块。

四、希望贵公司回复的信息

烦请初步说明：

1. 上述工作中贵公司可以独立承担哪些部分，哪些部分需要外协或由我方提供；
2. 为进行可制造性评审和初步报价，还需要我方提供哪些接口图、真空指标、尺寸公差和验收要求；
3. 是否可以先制作一个单通道探测器样机和一个三通道sector样机，测试通过后再生产全部设备；
4. 初步设计、样机制造、整机生产和验收的大致周期；
5. 是否能够提供设计、加工、总装和验收分项报价。

我们可以提供初步STEP模型、通道(每个sipm探测器)坐标表。当前模型为“仅供技术讨论，不可直接用于加工”。

补充说明：当前 afterSRC 模型只验证了扇区载架与固定支撑脱开的初始 12 mm 动作。后续平移、转姿并通过 ICF305 取出的完整连续路径仍需结合 STEP 进行装配/维护可达性评审，目前不应解读为已证明可完整取出。

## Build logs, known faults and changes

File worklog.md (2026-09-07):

# Worklog (Cross-Terminal)

Purpose: handoff index for all Codex terminals/agents working in this repository.

Entry Template:
- Timestamp UTC:
- Timestamp Local:
- Module/Scope:
- Command(s):
- Key Parameters/Overrides:
- Validation Result:
- Artifacts/State:
- Next Action:

## Entries

- Timestamp UTC: 2026-08-31T02:57:10Z
- Timestamp Local: 2026-08-31 11:57:10 JST
- Module/Scope: CompactInVacuum repository/source organization and cleanup
- Command(s): moved access studies under `compactInVacuum/studies/access_port/`; extracted `civ.access` and `civ.support`; `uv run --with pytest --with pyyaml pytest -q compactInVacuum/tests/test_platform_config.py compactInVacuum/tests/test_geometry.py`; `./compactInVacuum/run_freecad_tests.sh`; three study-local validate-only runs; canonical force rebuild; explicit `trash-put` cleanup.
- Key Parameters/Overrides: canonical root target unchanged; study-local index/state ownership; no geometry configuration changes during module extraction.
- Validation Result: pure-Python `41/41` pass; all FreeCAD runtime groups pass; ICF253/305/356 study states pass (`46/11/0`, `47/10/0`, `47/10/0`); canonical `47/10/0` pass. Canonical and pre-refactor ICF305 STEP share `214` solids, equal volume/area, and equal bounds.
- Artifacts/State: generated LaTeX build, review meshes, stale study states/backups, redundant GUI renderer, and Python caches moved to system trash and remain recoverable; formal FCStd/STEP/JSON/screenshots retained.
- Next Action: stage only the organized CompactInVacuum change set; keep unrelated physics/docs/supplier changes separate.

- Timestamp UTC: 2026-08-31T02:52:23Z
- Timestamp Local: 2026-08-31 11:52:23 JST
- Module/Scope: canonical afterSRC rebuild after repository/source reorganization
- Command(s): `./compactInVacuum/run_compactOne_afterSRC.sh --pipeline-index codex_targets.yaml --force-rebuild`
- Key Parameters/Overrides: root index contains canonical modules only; maintenance-access geometry moved to `civ.access`; stationary wall-mount geometry moved to `civ.support`; no configuration change.
- Validation Result: prototype non-strict pass (`47` pass, `10` warnings, `0` fail). Canonical and pre-refactor ICF305 study STEP both reopen valid with `214` solids, identical volume `12329451.8262 mm3`, area `2960800.541735 mm2`, and bounds `456.0 x 534.8 x 615.0 mm`.
- Artifacts/State: canonical FCStd/STEP/report/manifest/metrics regenerated; canonical state pass.
- Next Action: finalize cleanup audit and commit grouping.

- Timestamp UTC: 2026-08-31T02:47:37Z
- Timestamp Local: 2026-08-31 11:47:37 JST
- Module/Scope: reorganized afterSRC access-port ICF356 study validate-only
- Command(s): `compactInVacuum/studies/access_port/run_icf356.sh --validate-only --force-rebuild`
- Key Parameters/Overrides: study-local pipeline index/target/config/state; comparison output location unchanged.
- Validation Result: prototype non-strict pass (`47` pass, `10` warnings, `0` fail).
- Artifacts/State: new ignored state written to `compactInVacuum/studies/access_port/state/icf356.state.json`; all three reorganized study states are now current.
- Next Action: move obsolete root study states to trash and force-rebuild canonical ICF305.

- Timestamp UTC: 2026-08-31T02:43:31Z
- Timestamp Local: 2026-08-31 11:43:31 JST
- Module/Scope: reorganized afterSRC access-port ICF305 study validate-only
- Command(s): `compactInVacuum/studies/access_port/run_icf305.sh --validate-only --force-rebuild`
- Key Parameters/Overrides: study-local pipeline index/target/config/state; canonical geometry contract unchanged after access/support module extraction.
- Validation Result: prototype non-strict pass (`47` pass, `10` warnings, `0` fail).
- Artifacts/State: new ignored state written to `compactInVacuum/studies/access_port/state/icf305.state.json`; central report/manifest paths unchanged.
- Next Action: validate reorganized ICF356 study path.

- Timestamp UTC: 2026-08-31T02:39:23Z
- Timestamp Local: 2026-08-31 11:39:23 JST
- Module/Scope: reorganized afterSRC access-port ICF253 study validate-only
- Command(s): `compactInVacuum/studies/access_port/run_icf253.sh --validate-only --force-rebuild`
- Key Parameters/Overrides: study-local pipeline index/target/config/state tree; core geometry imported through new `civ.access` and `civ.support` modules.
- Validation Result: prototype non-strict pass (`46` pass, `11` warnings, `0` fail); rejected ICF253 passage warning retained.
- Artifacts/State: new ignored state written to `compactInVacuum/studies/access_port/state/icf253.state.json`; central report/manifest paths unchanged.
- Next Action: validate reorganized ICF305 study path.

- Timestamp UTC: 2026-08-30T14:00:55Z
- Timestamp Local: 2026-08-30 23:00:55 JST
- Module/Scope: corrected afterSRC permanent-support visual and artifact QA
- Command(s): `uv run --with pytest --with pyyaml pytest -q compactInVacuum/tests/test_platform_config.py compactInVacuum/tests/test_geometry.py`; `./compactInVacuum/run_freecad_tests.sh`; headless support-group mesh export/render; FreeCAD canonical STEP reopen; report/geometry-metrics audit.
- Key Parameters/Overrides: stationary supports rendered blue, ICF closure translucent red; UP pedestal bounds `x=[-220,-145], y=[160,200], z=[125.191,175.191] mm`.
- Validation Result: pure-Python `41/41` pass; all FreeCAD runtime groups pass; canonical report `47` pass / `10` warning / `0` fail; STEP reopens valid with `214` solids. All four holder-to-support and support-to-wall gaps are zero; support/pins/ground lift-corridor overlaps are zero.
- Artifacts/State: corrected standard views and comparison PNG regenerated; canonical state remains pass; no unrelated dirty worktree changes modified.
- Next Action: supplier/fabricator review of pedestal ribbing/fasteners and completion of the staged six-DOF extraction proof.

- Timestamp UTC: 2026-08-30T13:58:09Z
- Timestamp Local: 2026-08-30 22:58:09 JST
- Module/Scope: canonical corrected CompactInVacuum-afterSRC ICF305 fixed-support full export
- Command(s): `./compactInVacuum/run_compactOne_afterSRC.sh --pipeline-index codex_targets.yaml --force-rebuild`
- Key Parameters/Overrides: same corrected canonical configuration as the preceding validate-only run; removable closure carries no detector support/datum/ground ownership.
- Validation Result: prototype non-strict pass (`47` pass, `10` warnings, `0` fail). Load paths, permanent-wall contacts, ground bonds, lift-corridor clearance, LOS, target sweep, cable routing, and initial mount release pass; complete six-DOF extraction remains unresolved.
- Artifacts/State: canonical FCStd `1421433` bytes (`sha256=b0e09666...`), STEP `3151449` bytes (`sha256=84eadb4b...`, `55419` transfer entities), report/manifest/metrics regenerated under `compactInVacuum/artifacts/afterSRC/`; state pass.
- Next Action: render and inspect corrected support-focused views before handoff.

- Timestamp UTC: 2026-08-30T13:53:51Z
- Timestamp Local: 2026-08-30 22:53:51 JST
- Module/Scope: canonical corrected CompactInVacuum-afterSRC ICF305 fixed-support validate-only
- Command(s): `./compactInVacuum/run_compactOne_afterSRC.sh --pipeline-index codex_targets.yaml --validate-only --force-rebuild`
- Key Parameters/Overrides: canonical ICF305 with independent stationary wall supports, UP `-X` pedestal, holder-side dock, stationary locating pins, nonzero OFHC bonds, inward cable detours, and `12 mm` mount release.
- Validation Result: prototype non-strict pass (`47` pass, `10` warnings, `0` fail). All new structural/load-ownership checks and initial pin release pass; complete reorientation/top-lift remains an explicit strict-only warning.
- Artifacts/State: canonical validation report/manifest refreshed; `compactInVacuum/compactOne_afterSRC.state.json` pass.
- Next Action: perform the canonical full FCStd/STEP rebuild.

- Timestamp UTC: 2026-08-30T13:49:48Z
- Timestamp Local: 2026-08-30 22:49:48 JST
- Module/Scope: corrected CompactInVacuum-afterSRC ICF356 fixed-support comparison full export
- Command(s): `./compactInVacuum/run_compactOne_afterSRC_access_icf356.sh --pipeline-index codex_targets.yaml --force-rebuild`
- Key Parameters/Overrides: same stationary-pad support and nonzero ground-bond topology as corrected ICF305; ICF356 chamber remains `480 mm` long.
- Validation Result: prototype non-strict pass (`47` pass, `10` warnings, `0` fail); all structural/support/access ownership checks pass and detached-holder passage margin is `+74.561 mm`.
- Artifacts/State: corrected FCStd `1421852` bytes and STEP `3144289` bytes (`55263` transfer entities) exported under `compactInVacuum/artifacts/access_port_study/icf356/`; state pass.
- Next Action: validate and rebuild the canonical ICF305 artifact last.

- Timestamp UTC: 2026-08-30T13:45:42Z
- Timestamp Local: 2026-08-30 22:45:42 JST
- Module/Scope: corrected CompactInVacuum-afterSRC ICF305 fixed-support study full export
- Command(s): `./compactInVacuum/run_compactOne_afterSRC_access_icf305.sh --pipeline-index codex_targets.yaml --force-rebuild`
- Key Parameters/Overrides: removable UP holder ends at the inner dock near `x=-145 mm, y=180 mm`; stationary 75 mm `-X` wall pedestal remains with the chamber; LEFT/RIGHT/DOWN receive stationary 16 mm wall pads; all signal routes detour inward around the fixed supports.
- Validation Result: prototype non-strict pass (`47` pass, `10` warnings, `0` fail). Holder-to-pad, pad-to-real-wall, nonzero PE bond, access load ownership, cable clearance, `12 mm` inward release, and ICF305 passage (`+23.761 mm`) pass; continuous reorientation/top-lift remains unresolved.
- Artifacts/State: corrected FCStd `1421408` bytes and STEP `3151449` bytes (`55419` transfer entities) exported under `compactInVacuum/artifacts/access_port_study/icf305/`; state pass.
- Next Action: rebuild the corrected ICF356 comparison.

- Timestamp UTC: 2026-08-30T13:41:25Z
- Timestamp Local: 2026-08-30 22:41:25 JST
- Module/Scope: corrected CompactInVacuum-afterSRC ICF253 fixed-support comparison full export
- Command(s): `./compactInVacuum/run_compactOne_afterSRC_access_icf253.sh --pipeline-index codex_targets.yaml --force-rebuild`
- Key Parameters/Overrides: stationary wall supports added for all sectors; UP removable holder docks at `x=-145 mm, y=180 mm` to a stationary `-X` pedestal; nonzero OFHC ground bonds; `12 mm` inward pin-release stage.
- Validation Result: prototype non-strict pass (`46` pass, `11` warnings, `0` fail). Structural holder-to-support, support-to-wall, ground-to-wall, and load-free access checks pass; ICF253 remains rejected by the `-28.739 mm` flat-lift passage warning and also lacks the required supported-holder edge-on allowance.
- Artifacts/State: corrected FCStd `1419617` bytes and STEP `3122121` bytes (`54795` transfer entities) exported under `compactInVacuum/artifacts/access_port_study/icf253/`; state pass.
- Next Action: rebuild the corrected ICF305 study artifact.

- Timestamp UTC: 2026-08-30T09:10:32Z
- Timestamp Local: 2026-08-30 18:10:32 JST
- Module/Scope: CompactInVacuum-afterSRC access-port regression and visual QA
- Command(s): `uv run --with pytest --with pyyaml pytest -q compactInVacuum/tests/test_platform_config.py compactInVacuum/tests/test_geometry.py`; `./compactInVacuum/run_freecad_tests.sh`; headless FCStd mesh export and four-view rendering through `export_access_port_review_meshes.py` / `render_access_port_review_meshes.py`; FreeCAD STEP reopen audit.
- Key Parameters/Overrides: ICF253/305/356 candidate comparison; physical/purchased roles only in review images; keepouts remain in FCStd/JSON.
- Validation Result: pure-Python `41/41` pass; all FreeCAD runtime groups pass; four STEP files reopen as valid non-null compounds with `209` solids each; visual review confirms ICF305 is the balanced active layout and ICF356 has the tightest service margin.
- Artifacts/State: twelve standard-view PNGs plus `compactInVacuum/artifacts/access_port_study/afterSRC_access_port_comparison.png`; canonical ICF305 state remains pass and was not overwritten by rendering.
- Next Action: supplier review of the ICF305 fixed/blank flange drawings, weld-neck detail, structural analysis, and a continuous sector extraction demonstration.

- Timestamp UTC: 2026-08-30T08:57:37Z
- Timestamp Local: 2026-08-30 17:57:37 JST
- Module/Scope: canonical CompactInVacuum-afterSRC ICF305 maintenance-access full export
- Command(s): `./compactInVacuum/run_compactOne_afterSRC.sh --pipeline-index codex_targets.yaml --force-rebuild`
- Key Parameters/Overrides: active ICF305 all-metal access port; `251.0 mm` clear bore; OFHC copper gasket; `420 mm` chamber; helium leak acceptance target `<=1.0e-10 Pa m^3/s`; no elastomer seal.
- Validation Result: prototype non-strict pass (`41` pass, `10` warnings, `0` fail). Access flange fit, `14.056 mm` service clearance, `23.761 mm` conservative passage margin, nominal metal-seal topology, closed vacuum control volume, LOS, target sweep, and services pass; strict engineering release remains open on evidence gates.
- Artifacts/State: canonical FCStd `1399170` bytes (`sha256=ab9e1bf7...`), STEP `3132420` bytes (`sha256=b325736c...`, `55046` transfer entities), geometry metrics/report/manifest regenerated under `compactInVacuum/artifacts/afterSRC/`; `compactOne_afterSRC.state.json` pass.
- Next Action: render and visually inspect ICF253/305/356 standard comparison views, then audit final diffs and states.

- Timestamp UTC: 2026-08-30T08:54:22Z
- Timestamp Local: 2026-08-30 17:54:22 JST
- Module/Scope: canonical CompactInVacuum-afterSRC ICF305 maintenance-access validate-only
- Command(s): `./compactInVacuum/run_compactOne_afterSRC.sh --pipeline-index codex_targets.yaml --validate-only --force-rebuild`
- Key Parameters/Overrides: canonical profile now selects the all-metal top ICF305 port, OFHC copper gasket, `420 mm` chamber, and relocated top signal services.
- Validation Result: prototype non-strict pass (`41` pass, `10` warnings, `0` fail); all access integration geometry checks pass, while purchased drawings, structural release, materials, site envelope, and continuous extraction remain evidence warnings.
- Artifacts/State: `compactInVacuum/compactOne_afterSRC.state.json` is pass; canonical validation report and channel manifest refreshed under `compactInVacuum/artifacts/afterSRC/`.
- Next Action: run the canonical full build/export and retain ICF305 as the final active state.

- Timestamp UTC: 2026-08-30T08:51:26Z
- Timestamp Local: 2026-08-30 17:51:26 JST
- Module/Scope: CompactInVacuum-afterSRC ICF356 enlarged maintenance-access comparison full export
- Command(s): `./compactInVacuum/run_compactOne_afterSRC_access_icf356.sh --pipeline-index codex_targets.yaml --force-rebuild`
- Key Parameters/Overrides: same ICF356 all-metal enlarged-envelope comparison as the preceding validate-only run.
- Validation Result: prototype non-strict pass (`41` pass, `10` warnings, `0` fail); passage is roomy but service clearance is only `11.109 mm` and chamber length is `480 mm`.
- Artifacts/State: FCStd `1397226` bytes (`sha256=ca49df4a...`), STEP `3125258` bytes (`sha256=b3eb8322...`, `54890` transfer entities), geometry metrics/report/manifest exported under `compactInVacuum/artifacts/access_port_study/icf356/`; state pass.
- Next Action: rebuild the canonical afterSRC artifact with ICF305 selected.

- Timestamp UTC: 2026-08-30T08:48:15Z
- Timestamp Local: 2026-08-30 17:48:15 JST
- Module/Scope: CompactInVacuum-afterSRC ICF356 enlarged maintenance-access comparison validate-only
- Command(s): `./compactInVacuum/run_compactOne_afterSRC_access_icf356.sh --pipeline-index codex_targets.yaml --validate-only --force-rebuild`
- Key Parameters/Overrides: top `ICF356`, `301.8 mm` clear bore, OFHC copper gasket, `480 mm` chamber length, access center `(x,z)=(0,230) mm`, common relocated signal-port layout.
- Validation Result: prototype non-strict pass (`41` pass, `10` warnings, `0` fail); conservative flat-lift passage margin `+74.561 mm`, minimum service-port clearance `11.109 mm`; complete extraction remains unresolved.
- Artifacts/State: `compactInVacuum/compactOne_afterSRC_access_icf356.state.json` is pass; report and manifest refreshed under `compactInVacuum/artifacts/access_port_study/icf356/`.
- Next Action: run the ICF356 comparison full build/export.

- Timestamp UTC: 2026-08-30T08:45:20Z
- Timestamp Local: 2026-08-30 17:45:20 JST
- Module/Scope: CompactInVacuum-afterSRC ICF305 recommended maintenance-access full export
- Command(s): `./compactInVacuum/run_compactOne_afterSRC_access_icf305.sh --pipeline-index codex_targets.yaml --force-rebuild`
- Key Parameters/Overrides: same selected ICF305 all-metal access configuration as the preceding validate-only run.
- Validation Result: prototype non-strict pass (`41` pass, `10` warnings, `0` fail); access fit, service clearance, conservative passage, nominal metal-seal topology, and vacuum-control-volume closure pass.
- Artifacts/State: FCStd `1399025` bytes (`sha256=63ade0b8...`), STEP `3132420` bytes (`sha256=ec3110d0...`, `55046` transfer entities), geometry metrics/report/manifest exported under `compactInVacuum/artifacts/access_port_study/icf305/`; state pass.
- Next Action: validate the enlarged ICF356 comparison.

- Timestamp UTC: 2026-08-30T08:42:02Z
- Timestamp Local: 2026-08-30 17:42:02 JST
- Module/Scope: CompactInVacuum-afterSRC ICF305 recommended maintenance-access validate-only
- Command(s): `./compactInVacuum/run_compactOne_afterSRC_access_icf305.sh --pipeline-index codex_targets.yaml --validate-only --force-rebuild`
- Key Parameters/Overrides: top `ICF305`, `251.0 mm` clear bore, OFHC copper gasket, `420 mm` chamber length with upstream face retained, access center `(x,z)=(0,190) mm`, relocated signal ports.
- Validation Result: prototype non-strict pass (`41` pass, `10` warnings, `0` fail); conservative flat-lift passage margin `+23.761 mm`, minimum service-port clearance `14.056 mm`; continuous extraction remains unresolved.
- Artifacts/State: `compactInVacuum/compactOne_afterSRC_access_icf305.state.json` is pass; report and manifest refreshed under `compactInVacuum/artifacts/access_port_study/icf305/`.
- Next Action: run the ICF305 study full build/export.

- Timestamp UTC: 2026-08-30T08:39:05Z
- Timestamp Local: 2026-08-30 17:39:05 JST
- Module/Scope: CompactInVacuum-afterSRC ICF253 maintenance-access comparison full export
- Command(s): `./compactInVacuum/run_compactOne_afterSRC_access_icf253.sh --pipeline-index codex_targets.yaml --force-rebuild`
- Key Parameters/Overrides: same ICF253 all-metal comparison configuration as the preceding validate-only run.
- Validation Result: prototype non-strict pass (`40` pass, `11` warnings, `0` fail); ICF253 remains constrained by the `-28.739 mm` flat-lift screen.
- Artifacts/State: FCStd `1393591` bytes (`sha256=24cc4480...`), STEP `3103088` bytes (`sha256=67f09efa...`, `54422` transfer entities), geometry metrics/report/manifest exported under `compactInVacuum/artifacts/access_port_study/icf253/`; state pass.
- Next Action: validate the recommended ICF305 study profile.

- Timestamp UTC: 2026-08-30T08:35:22Z
- Timestamp Local: 2026-08-30 17:35:22 JST
- Module/Scope: CompactInVacuum-afterSRC ICF253 maintenance-access comparison validate-only
- Command(s): `./compactInVacuum/run_compactOne_afterSRC_access_icf253.sh --pipeline-index codex_targets.yaml --validate-only --force-rebuild`
- Key Parameters/Overrides: top `ICF253`, `198.5 mm` clear bore, OFHC copper gasket, `360 mm` chamber length, relocated signal ports, elastomer seal prohibited, helium leak requirement `<=1.0e-10 Pa m^3/s`.
- Validation Result: prototype non-strict pass (`40` pass, `11` warnings, `0` fail); flat-lift passage warning with `-28.739 mm` margin, while continuous reorientation/lift remains unresolved.
- Artifacts/State: `compactInVacuum/compactOne_afterSRC_access_icf253.state.json` is pass; validation report and channel manifest refreshed under `compactInVacuum/artifacts/access_port_study/icf253/`.
- Next Action: run the stateful full build/export for the ICF253 comparison artifact.

- Timestamp UTC: 2026-03-06T06:42:26Z
- Timestamp Local: 2026-03-06 15:42:26 JST
- Module/Scope: infrontofSamuraiMag (strict validate-only gate)
- Command(s): `./infrontofSamuraiMag/run_infrontofSamuraiMag.sh --pipeline-index codex_targets.yaml --validate-only --strict-validation`
- Key Parameters/Overrides: `strict=true`, default tolerances (`angle=0.05 deg`, `radius=0.2 mm`)
- Validation Result: pass
- Artifacts/State: `state.json.run.status=pass`, `validation.status=pass`, report refreshed
- Next Action: run full stateful build/export.

- Timestamp UTC: 2026-03-06T06:42:44Z
- Timestamp Local: 2026-03-06 15:42:44 JST
- Module/Scope: infrontofSamuraiMag (full run attempt)
- Command(s): `./infrontofSamuraiMag/run_infrontofSamuraiMag.sh --pipeline-index codex_targets.yaml`
- Key Parameters/Overrides: none
- Validation Result: pass (hash-skip path)
- Artifacts/State: `state.json.run.status=skipped`; previous valid state reused
- Next Action: force rebuild once to regenerate FCStd/STEP from new geometry.

- Timestamp UTC: 2026-03-06T06:43:16Z
- Timestamp Local: 2026-03-06 15:43:16 JST
- Module/Scope: infrontofSamuraiMag (forced full rebuild)
- Command(s): `./infrontofSamuraiMag/run_infrontofSamuraiMag.sh --pipeline-index codex_targets.yaml --force-rebuild`
- Key Parameters/Overrides: `force-rebuild=true`
- Validation Result: pass
- Artifacts/State: `state.json.run.status=pass`, `validation.status=pass`, FCStd/STEP/report regenerated
- Next Action: finalize code/test/doc summary for handoff.

- Timestamp UTC: 2026-03-06T07:52:05Z
- Timestamp Local: 2026-03-06 16:52:05 JST
- Module/Scope: infrontofSamuraiMag (tie-free detector base direct-mount rebuild)
- Command(s): `./infrontofSamuraiMag/run_infrontofSamuraiMag.sh --pipeline-index codex_targets.yaml --force-rebuild`
- Key Parameters/Overrides: `target/config updated for no-plate-tie mode`, `geometry.stand.enable_plate_ties=false`
- Validation Result: pass
- Artifacts/State: `state.json.run_id=20260306T075149Z-531213`, `state.json.run.status=pass`, `validation.status=pass`, STEP/FCStd regenerated
- Next Action: strict validate-only gate and report geometry delta.

- Timestamp UTC: 2026-03-06T07:52:08Z
- Timestamp Local: 2026-03-06 16:52:08 JST
- Module/Scope: infrontofSamuraiMag (strict validate-only gate after tie-free rebuild)
- Command(s): `./infrontofSamuraiMag/run_infrontofSamuraiMag.sh --pipeline-index codex_targets.yaml --validate-only --strict-validation`
- Key Parameters/Overrides: `strict=true`, `geometry.stand.enable_plate_ties=false`
- Validation Result: pass (hash-skip path)
- Artifacts/State: `state.json.run_id=20260306T075208Z-531295`, `state.json.run.status=skipped`, `validation.status=pass`
- Next Action: deliver user-facing change summary and next tuning options.

- Timestamp UTC: 2026-03-06T08:09:20Z
- Timestamp Local: 2026-03-06 17:09:20 JST
- Module/Scope: infrontofSamuraiMag (visual iteration: plate/mount proportion retune)
- Command(s): `./infrontofSamuraiMag/run_infrontofSamuraiMag.sh --pipeline-index codex_targets.yaml --force-rebuild`
- Key Parameters/Overrides: plate sizes + detector mount compacting params adjusted
- Validation Result: fail
- Artifacts/State: `state.json.run_id=20260306T080902Z-536294`, `run.status=fail`; failures at `los_all_occluders_clear` and `detector_mount_bridge_length_within_limit`
- Next Action: sync bridge-length validator with no-tie geometry and retune H plate envelope.

- Timestamp UTC: 2026-03-06T08:11:32Z
- Timestamp Local: 2026-03-06 17:11:32 JST
- Module/Scope: infrontofSamuraiMag (visual iteration v2 with validator sync)
- Command(s): `./infrontofSamuraiMag/run_infrontofSamuraiMag.sh --pipeline-index codex_targets.yaml --force-rebuild`
- Key Parameters/Overrides: H plate height rollback; bridge-length limit updated to include adapter span
- Validation Result: pass
- Artifacts/State: `state.json.run_id=20260306T081114Z-537333`, `run.status=pass`, STEP regenerated (`infrontofSamuraiMag.step`)
- Next Action: strict validate-only check and publish STEP path for user.

- Timestamp UTC: 2026-03-06T08:11:35Z
- Timestamp Local: 2026-03-06 17:11:35 JST
- Module/Scope: infrontofSamuraiMag (strict validate-only after visual iteration v2)
- Command(s): `./infrontofSamuraiMag/run_infrontofSamuraiMag.sh --pipeline-index codex_targets.yaml --validate-only --strict-validation`
- Key Parameters/Overrides: strict gate on, tie-free direct mount unchanged
- Validation Result: pass (hash-skip path)
- Artifacts/State: `state.json.run_id=20260306T081135Z-537415`, `run.status=skipped`, `validation.status=pass`
- Next Action: deliver updated STEP path and continue appearance tuning based on user feedback.

- Timestamp UTC: 2026-03-06T08:24:11Z
- Timestamp Local: 2026-03-06 17:24:11 JST
- Module/Scope: infrontofSamuraiMag (H plate x offset sign flip + unit audit batch)
- Command(s): `./infrontofSamuraiMag/run_infrontofSamuraiMag.sh --pipeline-index codex_targets.yaml --force-rebuild`
- Key Parameters/Overrides: `geometry.plate.h.offset_x_mm=-24.0`; unit audit confirms STEP length unit `SI_UNIT(.MILLI.,.METRE.)`; no cm auto-conversion
- Validation Result: pass
- Artifacts/State: FCStd/STEP regenerated (`infrontofSamuraiMag.step` size `5115537` bytes)
- Next Action: strict validate-only gate and publish refreshed STEP paths.

- Timestamp UTC: 2026-03-06T08:24:29Z
- Timestamp Local: 2026-03-06 17:24:29 JST
- Module/Scope: infrontofSamuraiMag (strict validate-only after H plate sign flip)
- Command(s): `./infrontofSamuraiMag/run_infrontofSamuraiMag.sh --pipeline-index codex_targets.yaml --validate-only --strict-validation`
- Key Parameters/Overrides: strict gate on; no additional geometry changes
- Validation Result: pass (hash-skip path)
- Artifacts/State: `state.json.run_id=20260306T082428Z-539880`, `run.status=skipped`, `validation.status=pass`
- Next Action: deliver implementation summary with unit-audit findings.

- Timestamp UTC: 2026-03-06T08:38:46Z
- Timestamp Local: 2026-03-06 17:38:46 JST
- Module/Scope: infrontofSamuraiMag (old-version plate placement preview, no plate cuts, overlap checks skipped)
- Command(s): `./infrontofSamuraiMag/run_infrontofSamuraiMag.sh --pipeline-index codex_targets.yaml --force-rebuild`
- Key Parameters/Overrides: target overrides set H/V1/V2 legacy placement+size (`sector_opening_deg=0`), `geometry.clearance.disable_plate_cuts=true`, `geometry.clearance.skip_overlap_checks=true`, `geometry.clearance.vv_min_gap_factor=1.0`
- Validation Result: fail (expected in preview mode for non-overlap checks: envelope/LOS/mount-hole envelope)
- Artifacts/State: `state.json.run_id=20260306T083727Z-541877`, `run.status=fail`, STEP regenerated (`sha256=42386645...`) and copied to root + old-version/transtostep
- Next Action: review visual result with user and decide whether to also relax LOS/envelope checks for preview pass.

- Timestamp UTC: 2026-03-06T08:43:38Z
- Timestamp Local: 2026-03-06 17:43:38 JST
- Module/Scope: infrontofSamuraiMag (legacy plate-center alignment correction)
- Command(s): `./infrontofSamuraiMag/run_infrontofSamuraiMag.sh --pipeline-index codex_targets.yaml --force-rebuild`
- Key Parameters/Overrides: legacy plate coordinates switched from old absolute frame to chamber-centered frame (`H: x=0,y=-60,z=330; V1: x=60,y=349.15,z=330; V2: x=-60,y=-409.15,z=330`)
- Validation Result: fail (preview mode still intentionally disables cuts/overlap checks; remaining LOS/envelope checks fail)
- Artifacts/State: `state.json.run_id=20260306T084305Z-542948`, STEP regenerated (`sha256=a171af58...`) and copied to root + old-version/transtostep
- Next Action: user visual confirmation of centering; then decide whether to keep this alignment or fine-tune Y/Z offsets.

- Timestamp UTC: 2026-03-06T10:41:24Z
- Timestamp Local: 2026-03-06 19:41:24 JST
- Module/Scope: infrontofSamuraiMag (freeze preview baseline to dedicated profile)
- Command(s): `./infrontofSamuraiMag/run_infrontofSamuraiMag.sh --pipeline-index codex_targets.yaml --force-rebuild`
- Key Parameters/Overrides: new profile `config/profiles/legacy_center_preview_locked.yaml`; `target.build.config` switched to profile; `target.build.overrides=[]`; `target.validation.strict=false`
- Validation Result: fail (expected for preview geometry), command exit=0 due non-strict gate
- Artifacts/State: `state.json.run_id=20260306T104059Z-556601`, `run.status=fail`, `validation.strict=false`, STEP `sha256=f3fa8e86...` synced to root and old-version path
- Next Action: perform incremental visual tuning with small parameter deltas on locked profile.

- Timestamp UTC: 2026-03-18T15:11:54Z
- Timestamp Local: 2026-03-19 00:11:54 JST
- Module/Scope: infrontofSamuraiMag (strict validate-only after rigid bridge / fixture-driven drilling update)
- Command(s): `./infrontofSamuraiMag/run_infrontofSamuraiMag.sh --pipeline-index codex_targets.yaml --validate-only --strict-validation`
- Key Parameters/Overrides: baseline + target intent updated for rigid bridge pose and direction-derived drilling; `strict=true`
- Validation Result: fail (`plates.los_all_occluders_clear` still fails in locked legacy preview); new detector checks `detector_mount_bridge_pose_fixed_relative_to_detector_body`, `detector_mount_hole_pattern_derived_from_fixture_direction`, and `detector_mount_plate_landing_within_envelope` pass
- Artifacts/State: `state.json.run_id=20260318T151148Z-7`, `run.status=fail`, `validation.status=fail`, report refreshed (`sha256=452275d3...`)
- Next Action: run full rebuild to export FCStd/STEP with the new mount semantics despite non-strict preview LOS failure.

- Timestamp UTC: 2026-03-18T15:12:13Z
- Timestamp Local: 2026-03-19 00:12:13 JST
- Module/Scope: infrontofSamuraiMag (force rebuild after rigid bridge / fixture-driven drilling update)
- Command(s): `./infrontofSamuraiMag/run_infrontofSamuraiMag.sh --pipeline-index codex_targets.yaml --force-rebuild`
- Key Parameters/Overrides: rigid bridge pose held relative to detector body; plate drilling now follows fixture direction; preview profile remains `strict=false`
- Validation Result: fail (same locked preview LOS blockers), command exit=0 due non-strict gate
- Artifacts/State: `state.json.run_id=20260318T151203Z-7`, `run.status=fail`, FCStd `sha256=61af516a...`, STEP `sha256=6eefd243...`, report `sha256=3d33ef52...`
- Next Action: continue visual/LOS tuning on the preview profile or promote the new detector mount semantics into a strict-pass geometry profile.

- Timestamp UTC: 2026-03-22T15:09:52Z
- Timestamp Local: 2026-03-23 00:09:52 JST
- Module/Scope: infrontofSamuraiMag (side-exit chamber + single rotary target strict gate)
- Command(s): `./infrontofSamuraiMag/run_infrontofSamuraiMag.sh --pipeline-index codex_targets.yaml --validate-only --strict-validation`
- Key Parameters/Overrides: active target switched to `config/profiles/side_exit_single_rotary_strict.yaml`; chamber `220x220x1200 mm`; `los_scope=v2_fullpath`; single rotary target enabled; detector support plates tightened to `H.y=360 mm`, `V1.x=360 mm`, `V2.x=-360 mm`; stand feet moved to base-footprint corners to clear side-exit detector corridors.
- Validation Result: pass (strict gate green across chamber/plates/detector/target/stand)
- Artifacts/State: `state.json.run_id=20260322T150952Z-7`, `run.status=pass`, `validation.status=pass`, report refreshed (`sha256=268a7f29...`)
- Next Action: run full rebuild to regenerate FCStd/STEP artifacts from the new strict-pass profile.

- Timestamp UTC: 2026-03-22T15:10:22Z
- Timestamp Local: 2026-03-23 00:10:22 JST
- Module/Scope: infrontofSamuraiMag (export artifacts for side-exit chamber + single rotary target strict-pass geometry)
- Command(s): `./infrontofSamuraiMag/run_infrontofSamuraiMag.sh --pipeline-index codex_targets.yaml --force-rebuild`
- Key Parameters/Overrides: same strict profile as validate-only run; detector-vs-assembly overlap now distance-filtered before boolean common-volume acceptance to suppress false chamber overlaps; FCStd/STEP regenerated from strict-pass geometry.
- Validation Result: pass
- Artifacts/State: `state.json.run_id=20260322T151022Z-7`, `run.status=pass`, FCStd `sha256=731b6211...`, STEP `sha256=dc6bd74a...`, report `sha256=268a7f29...`
- Next Action: hand off updated target/config/code changes and strict-pass artifacts to the user for review.

- Timestamp UTC: 2026-03-22T16:02:28Z
- Timestamp Local: 2026-03-23 01:02:28 JST
- Module/Scope: infrontofSamuraiMag (continuous rounded-slot plates + rear VF80 strict gate)
- Command(s): `./infrontofSamuraiMag/run_infrontofSamuraiMag.sh --pipeline-index codex_targets.yaml --validate-only --strict-validation`
- Key Parameters/Overrides: H/V/V detector windows rebuilt as continuous rounded slots; `rear` end module reduced from `VF150` to `VF80`; `front` kept at `VG150`; end-module groove semantics parameterized by `VG/VF` type; plate hard cutout skipped for rounded-slot plates so each plate remains a single continuous solid.
- Validation Result: pass (strict gate green across chamber/plates/detector/target/stand)
- Artifacts/State: `state.json.run_id=20260322T160228Z-7`, `run.status=pass`, `validation.status=pass`, report refreshed (`sha256=b5e69e46...`)
- Next Action: run full rebuild to export FCStd/STEP artifacts for the new rear-80A and continuous-slot geometry.

- Timestamp UTC: 2026-03-22T16:02:57Z
- Timestamp Local: 2026-03-23 01:02:57 JST
- Module/Scope: infrontofSamuraiMag (export artifacts for continuous rounded-slot plates + rear VF80)
- Command(s): `./infrontofSamuraiMag/run_infrontofSamuraiMag.sh --pipeline-index codex_targets.yaml --force-rebuild`
- Key Parameters/Overrides: same strict profile as validate-only run; rebuilt FCStd/STEP after splitting end-module config into `front/rear`, changing `rear` to `VF80`, and replacing fragmented plate openings with single-solid rounded-slot plates.
- Validation Result: pass
- Artifacts/State: `state.json.run_id=20260322T160257Z-7`, `run.status=pass`, FCStd `sha256=4727cff4...`, STEP `sha256=326f132a...`, report `sha256=b5e69e46...`
- Next Action: hand off the updated strict-pass geometry and artifacts for visual review.

- Timestamp UTC: 2026-03-22T16:28:28Z
- Timestamp Local: 2026-03-23 01:28:28 JST
- Module/Scope: infrontofSamuraiMag (photo-like plate relocation strict gate)
- Command(s): `./infrontofSamuraiMag/run_infrontofSamuraiMag.sh --pipeline-index codex_targets.yaml --validate-only --strict-validation`
- Key Parameters/Overrides: active target kept on `config/profiles/side_exit_single_rotary_strict.yaml`; horizontal plate flipped to `-y`; manual offsets tightened to `H.y=-305 mm`, `V1.x=125 mm`, `V2.x=-125 mm`; plate cuts remain limited to chamber/LOS openings only.
- Validation Result: pass (strict gate green across chamber/plates/detector/target/stand)
- Artifacts/State: `state.json.run_id=20260322T162828Z-7`, `run.status=pass`, `validation.status=pass`, report refreshed (`sha256=ea28a1b4...`)
- Next Action: run force rebuild to export FCStd/STEP artifacts for the new photo-like plate placement.

- Timestamp UTC: 2026-03-22T16:28:58Z
- Timestamp Local: 2026-03-23 01:28:58 JST
- Module/Scope: infrontofSamuraiMag (export artifacts for photo-like plate relocation)
- Command(s): `./infrontofSamuraiMag/run_infrontofSamuraiMag.sh --pipeline-index codex_targets.yaml --force-rebuild`
- Key Parameters/Overrides: same strict profile as preceding validate-only run; rebuilt FCStd/STEP after flipping `H` to the `-y` side and pulling all three plates inboard to the first strict-pass offsets plus 5 mm manufacturing margin.
- Validation Result: pass
- Artifacts/State: `state.json.run_id=20260322T162858Z-7`, `run.status=pass`, FCStd `sha256=93b99e26...`, STEP `sha256=85706800...`, report `sha256=ea28a1b4...`
- Next Action: hand off the updated strict-pass geometry for visual review against the reference photo.

- Timestamp UTC: 2026-03-22T16:52:20Z
- Timestamp Local: 2026-03-23 01:52:20 JST
- Module/Scope: infrontofSamuraiMag (true target-to-detector LOS tube plate openings strict gate)
- Command(s): `./infrontofSamuraiMag/run_infrontofSamuraiMag.sh --pipeline-index codex_targets.yaml --validate-only --strict-validation`
- Key Parameters/Overrides: active profile kept on `config/profiles/side_exit_single_rotary_strict.yaml`; `geometry.plate.{h,v1,v2}.opening_style` switched from `rounded_slot` to `los_tube`; plate cut generation now uses true `active_target -> detector_active_face` LOS tubes instead of detector-to-plate orthogonal projections; current photo-like plate offsets retained.
- Validation Result: pass (strict gate green across chamber/plates/detector/target/stand)
- Artifacts/State: `state.json.run_id=20260322T165220Z-7`, `run.status=pass`, `validation.status=pass`, report refreshed (`sha256=817383cb...`)
- Next Action: run force rebuild to export FCStd/STEP artifacts for the true LOS-tube opening geometry.

- Timestamp UTC: 2026-03-22T16:52:48Z
- Timestamp Local: 2026-03-23 01:52:48 JST
- Module/Scope: infrontofSamuraiMag (export artifacts for true target-to-detector LOS tube plate openings)
- Command(s): `./infrontofSamuraiMag/run_infrontofSamuraiMag.sh --pipeline-index codex_targets.yaml --force-rebuild`
- Key Parameters/Overrides: same strict profile as preceding validate-only run; regenerated FCStd/STEP after replacing projection-based continuous slots with target-to-detector LOS tube cuts; validation report shows `plate_opening_geometry_valid` as `style=los_tube` with `plane_hits=0` for all three offset HVV plates.
- Validation Result: pass
- Artifacts/State: `state.json.run_id=20260322T165248Z-7`, `run.status=pass`, FCStd `sha256=f8ba3d1f...`, STEP `sha256=d9b1ad5b...`, report `sha256=817383cb...`
- Next Action: hand off the corrected LOS-based plate geometry and confirm whether any residual stand anchor slots should be removed for aesthetics.

- Timestamp UTC: 2026-03-22T17:11:49Z
- Timestamp Local: 2026-03-23 02:11:49 JST
- Module/Scope: infrontofSamuraiMag (photo-like plate-hugging layout, remove monolithic stand base plate, add H rectangular relief holes)
- Command(s): `./infrontofSamuraiMag/run_infrontofSamuraiMag.sh --pipeline-index codex_targets.yaml --validate-only --strict-validation`
- Key Parameters/Overrides: updated active strict profile to `H.y=-125 mm`, `V1.x=125 mm`, `V2.x=-125 mm`; `geometry.stand.with_base_plate=false`; first draft of H rectangular relief generation used detector-package/LOS intersections to clear lower detectors while keeping true LOS semantics.
- Validation Result: fail (`plates.single_continuous_plate_solids` failed because `HPlate` was cut into `2` solids by an over-wide relief window)
- Artifacts/State: `state.json.run_id=20260322T171149Z-7`, `run.status=fail`, `validation.status=fail`, report `sha256=ad1442b4...`
- Next Action: tighten H relief generation so only the real lower-detector package/LOS intersections are cut and recover a single continuous H plate.

- Timestamp UTC: 2026-03-22T17:18:21Z
- Timestamp Local: 2026-03-23 02:18:21 JST
- Module/Scope: infrontofSamuraiMag (export corrected photo-like HVV layout with no monolithic stand base plate)
- Command(s): `./infrontofSamuraiMag/run_infrontofSamuraiMag.sh --pipeline-index codex_targets.yaml --force-rebuild`
- Key Parameters/Overrides: kept `H.y=-125 mm`, removed `StandBasePlate`, regenerated H rectangular reliefs using package bbox crossing the actual H-plate thickness plus true LOS plane hits; relief windows settled to two local rectangles instead of one full-height slot.
- Validation Result: pass
- Artifacts/State: `state.json.run_id=20260322T171821Z-7`, `run.status=pass`, FCStd `sha256=b7f2d710...`, STEP `sha256=f84bd5d9...`, report `sha256=fa7f7c52...`
- Next Action: run one more strict validate-only confirmation and then hand off the rebuilt geometry for visual review.

- Timestamp UTC: 2026-03-22T17:19:59Z
- Timestamp Local: 2026-03-23 02:19:59 JST
- Module/Scope: infrontofSamuraiMag (post-rebuild strict confirmation for the photo-like HVV layout)
- Command(s): `./infrontofSamuraiMag/run_infrontofSamuraiMag.sh --pipeline-index codex_targets.yaml --validate-only --strict-validation`
- Key Parameters/Overrides: unchanged target hash after the successful rebuild; stateful runner reused the current strict-pass artifacts and validation report.
- Validation Result: pass via hash-skip (`run.status=skipped`, `validation.status=pass`)
- Artifacts/State: `state.json.run_id=20260322T171959Z-7`, FCStd `sha256=b7f2d710...`, STEP `sha256=f84bd5d9...`, report `sha256=fa7f7c52...`
- Next Action: deliver the updated chamber-hugging three-plate geometry and collect user review on plate aesthetics.

- Timestamp UTC: 2026-03-26T06:18:28Z
- Timestamp Local: 2026-03-26 15:18:28 JST
- Module/Scope: infrontofSamuraiMag (strict validate-only after switching to upstream VF100 / downstream VG80 and extending chamber z)
- Command(s): `./infrontofSamuraiMag/run_infrontofSamuraiMag.sh --pipeline-index codex_targets.yaml --validate-only --strict-validation`
- Key Parameters/Overrides: requirement baseline + active strict profile updated to `front=VF100`, `rear=VG80`, `chamber.core.size_z_mm=1300.0`; `VG` remains groove-face and `VF` remains flat-face.
- Validation Result: pass (strict gate green across chamber/plates/detector/target/stand)
- Artifacts/State: `state.json.run_id=20260326T061828Z-7`, `run.status=pass`, `validation.status=pass`, report refreshed (`sha256=3c20d74e...`)
- Next Action: run force rebuild to regenerate FCStd/STEP artifacts for the new flange pairing and longer chamber.

- Timestamp UTC: 2026-03-26T06:19:26Z
- Timestamp Local: 2026-03-26 15:19:26 JST
- Module/Scope: infrontofSamuraiMag (export artifacts for VF100/VG80 interfaces with `size_z_mm=1300`)
- Command(s): `./infrontofSamuraiMag/run_infrontofSamuraiMag.sh --pipeline-index codex_targets.yaml --force-rebuild`
- Key Parameters/Overrides: same strict profile as preceding validate-only run; front module rebuilt as flat-face `VF100`, rear module rebuilt as groove-face `VG80`, chamber core length increased to `1300 mm`; FreeCAD cache-create warnings were non-blocking under sandbox.
- Validation Result: pass
- Artifacts/State: `state.json.run_id=20260326T061926Z-7`, `run.status=pass`, FCStd `sha256=9ed945d2...`, STEP `sha256=c5f5e76f...`, report `sha256=10e345cb...`
- Next Action: hand off updated artifact paths and validation result for user review.

- Timestamp UTC: 2026-03-26T06:44:20Z
- Timestamp Local: 2026-03-26 15:44:20 JST
- Module/Scope: infrontofSamuraiMag (strict validate-only for target-center-to-detector-front-face conical chamber cuts, first pass)
- Command(s): `./infrontofSamuraiMag/run_infrontofSamuraiMag.sh --pipeline-index codex_targets.yaml --validate-only --strict-validation`
- Key Parameters/Overrides: chamber/rear-end-module side-exit cuts switched from fixed-diameter LOS cylinders to cones from `active_target_center` to each detector front-face circle; validator LOS segment start was also moved to `active_target_center` in this first pass.
- Validation Result: fail (`plates.los_all_occluders_clear` reported `SingleTarget` / `TargetRotaryArm` blockers once the LOS ray itself also started at the target center)
- Artifacts/State: `state.json.run_id=20260326T064420Z-7`, `run.status=fail`, `validation.status=fail`, report refreshed (`sha256=525a1fb0...`)
- Next Action: keep the conical chamber cuts but restore LOS reporting/segment start to the existing `source_plane` semantics so strict gate continues to test external occluders instead of source-side target hardware.

- Timestamp UTC: 2026-03-26T06:46:04Z
- Timestamp Local: 2026-03-26 15:46:04 JST
- Module/Scope: infrontofSamuraiMag (strict validate-only after keeping conical chamber cuts and reverting LOS ray start semantics)
- Command(s): `./infrontofSamuraiMag/run_infrontofSamuraiMag.sh --pipeline-index codex_targets.yaml --validate-only --strict-validation`
- Key Parameters/Overrides: chamber/rear-end-module geometry still uses `active_target_center -> detector front-face circle` cones; `los_all_occluders_clear` detail now reports `chamber_opening=cone_to_detector_front_face_circle` while the v2 LOS check itself reuses the prior `source_plane -> detector_active_face` segment start.
- Validation Result: pass (strict gate green across chamber/plates/detector/target/stand)
- Artifacts/State: `state.json.run_id=20260326T064604Z-7`, `run.status=pass`, `validation.status=pass`, report refreshed (`sha256=f18a6a50...`)
- Next Action: run force rebuild to export FCStd/STEP artifacts for the conical chamber-opening geometry.

- Timestamp UTC: 2026-03-26T06:46:52Z
- Timestamp Local: 2026-03-26 15:46:52 JST
- Module/Scope: infrontofSamuraiMag (export artifacts for conical chamber side-exit openings)
- Command(s): `./infrontofSamuraiMag/run_infrontofSamuraiMag.sh --pipeline-index codex_targets.yaml --force-rebuild`
- Key Parameters/Overrides: same strict profile as preceding validate-only run; chamber and rear end module now cut by target-center-to-detector-front-face cones instead of fixed-radius LOS cylinders; FreeCAD cache-create warnings remained non-blocking under sandbox.
- Validation Result: pass
- Artifacts/State: `state.json.run_id=20260326T064652Z-7`, `run.status=pass`, FCStd `sha256=4de79d3d...`, STEP `sha256=5ba103a4...`, report `sha256=213ed2ff...`
- Next Action: hand off the conical chamber-opening geometry and updated artifact paths for user review.

- Timestamp UTC: 2026-03-26T06:57:48Z
- Timestamp Local: 2026-03-26 15:57:48 JST
- Module/Scope: infrontofSamuraiMag (strict validate-only after extending chamber z from 1400 mm request baseline)
- Command(s): `./infrontofSamuraiMag/run_infrontofSamuraiMag.sh --pipeline-index codex_targets.yaml --validate-only --strict-validation`
- Key Parameters/Overrides: current strict side-exit baseline/profile updated from `chamber.core.size_z_mm=1300.0` to `1400.0`; flange pairing and conical chamber openings unchanged.
- Validation Result: pass (strict gate green across chamber/plates/detector/target/stand)
- Artifacts/State: `state.json.run_id=20260326T065748Z-7`, `run.status=pass`, `validation.status=pass`, report refreshed (`sha256=59cabf3e...`)
- Next Action: run force rebuild to regenerate FCStd/STEP artifacts for the longer chamber.

- Timestamp UTC: 2026-03-26T06:58:36Z
- Timestamp Local: 2026-03-26 15:58:36 JST
- Module/Scope: infrontofSamuraiMag (export artifacts for chamber `size_z_mm=1400`)
- Command(s): `./infrontofSamuraiMag/run_infrontofSamuraiMag.sh --pipeline-index codex_targets.yaml --force-rebuild`
- Key Parameters/Overrides: same strict profile as preceding validate-only run; chamber core length increased by another `100 mm` to `1400 mm`; VF100/VG80 interfaces and conical side-exit openings retained; FreeCAD cache-create warnings remained non-blocking under sandbox.
- Validation Result: pass
- Artifacts/State: `state.json.run_id=20260326T065836Z-7`, `run.status=pass`, FCStd `sha256=1793b963...`, STEP `sha256=91983282...`, report `sha256=3458321a...`
- Next Action: hand off refreshed artifact paths and validation result for the 1400 mm chamber.

- Timestamp UTC: 2026-03-26T07:18:10Z
- Timestamp Local: 2026-03-26 16:18:10 JST
- Module/Scope: infrontofSamuraiMag (strict validate-only after switching to welded pipe-stub JIS interfaces and shrinking chamber footprint)
- Command(s): `./infrontofSamuraiMag/run_infrontofSamuraiMag.sh --pipeline-index codex_targets.yaml --validate-only --strict-validation`
- Key Parameters/Overrides: chamber core tightened to `185 x 185 x 1400 mm`; end-module stack changed to `chamber -> welded round pipe stub -> JIS flange -> mating equipment`; `front=VF100` flat with `pipe_len=10 mm`, `rear=VG80` grooved with `pipe_len=20 mm`; groove/seal face moved to the outward equipment-side interface face; active target kept at `(0,0,0)`.
- Validation Result: pass (strict gate green across chamber/plates/detector/target/stand, including `welded_pipe_stub_to_jis_flange`, `vacuum_boundary_complete`, and `los_all_occluders_clear`)
- Artifacts/State: `state.json.run_id=20260326T071810Z-7`, `run.status=pass`, `validation.status=pass`, report refreshed (`sha256=88481da3...`)
- Next Action: run force rebuild to export FCStd/STEP artifacts for the welded-pipe-stub interface geometry.

- Timestamp UTC: 2026-03-26T07:19:03Z
- Timestamp Local: 2026-03-26 16:19:03 JST
- Module/Scope: infrontofSamuraiMag (export artifacts for welded pipe-stub VF100/VG80 interfaces and reduced `185 x 185` chamber core)
- Command(s): `./infrontofSamuraiMag/run_infrontofSamuraiMag.sh --pipeline-index codex_targets.yaml --force-rebuild`
- Key Parameters/Overrides: same strict profile as preceding validate-only run; front/rear end modules rebuilt as welded pipe stub plus JIS flange assemblies (`front pipe=10 mm`, `rear pipe=20 mm`); chamber transverse footprint reduced to `185 x 185 mm`; FreeCAD cache-create warnings remained non-blocking under sandbox.
- Validation Result: pass
- Artifacts/State: `state.json.run_id=20260326T071903Z-7`, `run.status=pass`, FCStd `sha256=3001c758...`, STEP `sha256=8227d300...`, report `sha256=9b87c1ad...`
- Next Action: hand off the new artifact paths and the welded-pipe-stub interface semantics for user review.

- Timestamp UTC: 2026-03-26T07:33:27Z
- Timestamp Local: 2026-03-26 16:33:27 JST
- Module/Scope: infrontofSamuraiMag (strict validate-only after shortening only the left/upstream chamber span and lengthening the front pipe stub)
- Command(s): `./infrontofSamuraiMag/run_infrontofSamuraiMag.sh --pipeline-index codex_targets.yaml --validate-only --strict-validation`
- Key Parameters/Overrides: chamber core changed to asymmetric z placement with `size_z_mm=1300.0`, `center_z_mm=50.0`, so chamber faces sit at `z=[-600,+700] mm` and the right/downstream side stays unchanged; `front=VF100` welded pipe stub lengthened to `100 mm`; `rear=VG80` pipe stub kept at `20 mm`; target remains at `(0,0,0)`.
- Validation Result: pass (strict gate green across chamber/plates/detector/target/stand, including `welded_pipe_stub_to_jis_flange`, `channel_first_exit_face_by_sector`, `vacuum_boundary_complete`, and `los_all_occluders_clear`)
- Artifacts/State: `state.json.run_id=20260326T073327Z-7`, `run.status=pass`, `validation.status=pass`, report refreshed (`sha256=fa05ad39...`)
- Next Action: run force rebuild to export FCStd/STEP artifacts for the asymmetric-z chamber and longer front pipe.

- Timestamp UTC: 2026-03-26T07:34:20Z
- Timestamp Local: 2026-03-26 16:34:20 JST
- Module/Scope: infrontofSamuraiMag (export artifacts for asymmetric-z chamber with longer front VF100 pipe stub)
- Command(s): `./infrontofSamuraiMag/run_infrontofSamuraiMag.sh --pipeline-index codex_targets.yaml --force-rebuild`
- Key Parameters/Overrides: same strict profile as preceding validate-only run; upstream/left chamber side shortened by `100 mm` while downstream/right side is held fixed; front welded pipe stub increased to `100 mm`; rear welded pipe stub kept at `20 mm`; FreeCAD cache-create warnings remained non-blocking under sandbox.
- Validation Result: pass
- Artifacts/State: `state.json.run_id=20260326T073420Z-7`, `run.status=pass`, FCStd `sha256=f8e4f730...`, STEP `sha256=cce44615...`, report `sha256=49a388c5...`
- Next Action: hand off the rebuilt asymmetric-z chamber artifacts for visual review against the screenshot.

- Timestamp UTC: 2026-03-26T07:53:12Z
- Timestamp Local: 2026-03-26 16:53:12 JST
- Module/Scope: infrontofSamuraiMag (strict validate-only for chamber left face `z=-200 mm`)
- Command(s): `./infrontofSamuraiMag/run_infrontofSamuraiMag.sh --pipeline-index codex_targets.yaml --validate-only --strict-validation`
- Key Parameters/Overrides: chamber core updated to `size_z_mm=900.0`, `center_z_mm=250.0`, so faces sit at `z=[-200,+700] mm`; front `VF100` pipe stub kept long at `100 mm`; initial attempt moved `main_pump / gauge_safety / spare` to positive-z positions inside the shorter shell.
- Validation Result: fail (`plates.los_all_occluders_clear`; blockers were `GaugeSafetyPort` for `left_deuteron` and `MainPumpPort` for `right_deuteron/right_proton_large`)
- Artifacts/State: `state.json.run_id=20260326T075312Z-7`, `run.status=fail`, `validation.status=fail`, report refreshed (`sha256=d32d2625...`)
- Next Action: move the side-wall ports back upstream within the shorter shell so they remain inside the chamber span without blocking detector LOS.

- Timestamp UTC: 2026-03-26T07:54:51Z
- Timestamp Local: 2026-03-26 16:54:51 JST
- Module/Scope: infrontofSamuraiMag (strict validate-only after upstream-side port reposition for left face `z=-200 mm`)
- Command(s): `./infrontofSamuraiMag/run_infrontofSamuraiMag.sh --pipeline-index codex_targets.yaml --validate-only --strict-validation`
- Key Parameters/Overrides: chamber faces remain `z=[-200,+700] mm`; front pipe stub remains `100 mm`; `main_pump / gauge_safety / spare` repositioned to `center_z_mm=-120 / -140 / -160` so they fit inside the shortened shell and clear side-exit LOS.
- Validation Result: pass (strict gate green across chamber/plates/detector/target/stand, including `welded_pipe_stub_to_jis_flange`, `channel_first_exit_face_by_sector`, `vacuum_boundary_complete`, and `los_all_occluders_clear`)
- Artifacts/State: `state.json.run_id=20260326T075451Z-7`, `run.status=pass`, `validation.status=pass`, report refreshed (`sha256=f3a0c484...`)
- Next Action: run force rebuild to export FCStd/STEP artifacts for the `z=[-200,+700] mm` chamber.

- Timestamp UTC: 2026-03-26T07:55:41Z
- Timestamp Local: 2026-03-26 16:55:41 JST
- Module/Scope: infrontofSamuraiMag (export artifacts for chamber left face `z=-200 mm` and longer front VF100 pipe stub)
- Command(s): `./infrontofSamuraiMag/run_infrontofSamuraiMag.sh --pipeline-index codex_targets.yaml --force-rebuild`
- Key Parameters/Overrides: same strict profile as preceding validate-only run; chamber remains asymmetric with faces `z=[-200,+700] mm`; front welded pipe stub stays `100 mm`; rear welded pipe stub stays `20 mm`; side-wall ports remain at `-120 / -140 / -160 mm`; FreeCAD cache-create warnings remained non-blocking under sandbox.
- Validation Result: pass
- Artifacts/State: `state.json.run_id=20260326T075541Z-7`, `run.status=pass`, FCStd `sha256=70d5385e...`, STEP `sha256=2ea29dba...`, report `sha256=76f1627c...`
- Next Action: hand off the rebuilt artifacts for visual confirmation of the shortened left chamber side.

- Timestamp UTC: 2026-03-26T08:08:21Z
- Timestamp Local: 2026-03-26 17:08:21 JST
- Module/Scope: infrontofSamuraiMag (post-export-fix strict validate-only check)
- Command(s): `./infrontofSamuraiMag/run_infrontofSamuraiMag.sh --pipeline-index codex_targets.yaml --validate-only --strict-validation`
- Key Parameters/Overrides: target/spec unchanged; export code now uses writable XDG cache/config roots and FCStd round-trip reopen validation, but skip optimization still keys off target hash so validate-only reused the current accepted state.
- Validation Result: skipped + pass (`validation.status=pass`, strict gate remains green for the previously rebuilt geometry/report)
- Artifacts/State: `state.json.run_id=20260326T080821Z-8`, `run.status=skipped`, report reused (`sha256=76f1627c...`)
- Next Action: run `--force-rebuild` so the FCStd export fix is materialized into fresh artifacts despite the unchanged target hash.

- Timestamp UTC: 2026-03-26T08:08:29Z
- Timestamp Local: 2026-03-26 17:08:29 JST
- Module/Scope: infrontofSamuraiMag (force rebuild after FCStd export pipeline fix)
- Command(s): `./infrontofSamuraiMag/run_infrontofSamuraiMag.sh --pipeline-index codex_targets.yaml --force-rebuild`
- Key Parameters/Overrides: same asymmetric chamber geometry (`z=[-200,+700] mm`); `run_infrontofSamuraiMag.sh` now sets writable `XDG_CACHE_HOME/XDG_CONFIG_HOME` under `/tmp/infrontofSamuraiMag-freecad`; `export.py` now exports STEP first, then saves FCStd, closes the source doc, and reopens the saved FCStd to verify all exported objects survive the round-trip with non-null shapes.
- Validation Result: pass
- Artifacts/State: `state.json.run_id=20260326T080829Z-8`, `run.status=pass`, FCStd `sha256=adc15199...`, STEP `sha256=b07f1958...`, report `sha256=76f1627c...`
- Next Action: hand off the rebuilt FCStd/STEP pair and note that future code-only export changes still require `--force-rebuild` when target hash is unchanged.

- Timestamp UTC: 2026-03-26T08:16:27Z
- Timestamp Local: 2026-03-26 17:16:27 JST
- Module/Scope: infrontofSamuraiMag (force rebuild after GUI-backed FCStd persistence fix)
- Command(s): `./infrontofSamuraiMag/run_infrontofSamuraiMag.sh --pipeline-index codex_targets.yaml --force-rebuild`
- Key Parameters/Overrides: `run_infrontofSamuraiMag.sh` now also sets `QT_QPA_PLATFORM=offscreen`, `QT_OPENGL=software`, and `LIBGL_ALWAYS_SOFTWARE=1`; `cli.py` now enables `FreeCADGui.showMainWindow()` before model build whenever `fcstd` export is requested; `export.py` now fits an isometric GUI view, forces all generated solids visible in tree/viewport, and rejects any FCStd archive that lacks `GuiDocument.xml`.
- Validation Result: pass
- Artifacts/State: `state.json.run_id=20260326T081627Z-8`, `run.status=pass`, FCStd `sha256=1f1e6481...`, STEP `sha256=b07f1958...`, report `sha256=76f1627c...`; regenerated FCStd size increased to `953068` bytes and now contains both `Document.xml` and `GuiDocument.xml`.
- Next Action: hand off the GUI-complete FCStd artifact for user-side reopen verification in desktop FreeCAD.

- Timestamp UTC: 2026-03-26T08:32:27Z
- Timestamp Local: 2026-03-26 17:32:27 JST
- Module/Scope: infrontofSamuraiMag (strict validate-only after moving the four support feet into chamber/H centered rows)
- Command(s): `./infrontofSamuraiMag/run_infrontofSamuraiMag.sh --pipeline-index codex_targets.yaml --validate-only --strict-validation`
- Key Parameters/Overrides: support-foot layout no longer uses far outer corners; current geometry freezes four feet into two rows: chamber row `z=250 mm, x=±50 mm` and H-row `z=620 mm, x=-24±160 mm`.
- Validation Result: pass
- Artifacts/State: `state.json.run_id=20260326T083227Z-8`, `run.status=pass`, report refreshed (`sha256=e0a4e5ca...`); new stand check `support_rows_centered_under_chamber_and_h_plate` passed with detail `chamber_row=z=250.000, x=[-50.0, 50.0]; h_row=z=620.000, x=[-184.0, 136.0]`.
- Next Action: run force rebuild to refresh FCStd/STEP artifacts with the centered four-foot support layout.

- Timestamp UTC: 2026-03-26T08:33:21Z
- Timestamp Local: 2026-03-26 17:33:21 JST
- Module/Scope: infrontofSamuraiMag (force rebuild after centered four-foot support layout update)
- Command(s): `./infrontofSamuraiMag/run_infrontofSamuraiMag.sh --pipeline-index codex_targets.yaml --force-rebuild`
- Key Parameters/Overrides: same strict chamber/plate/detector geometry as previous pass; stand support feet now materialize at `(-50,250)`, `(50,250)`, `(-184,620)`, `(136,620)` in `x/z` projection, i.e. two under chamber and two under `H` plate instead of four remote outer-corner feet.
- Validation Result: pass
- Artifacts/State: `state.json.run_id=20260326T083321Z-8`, `run.status=pass`, FCStd `sha256=0dc80c6b...`, STEP `sha256=66e3e71e...`, report `sha256=e7215060...`
- Next Action: hand off the rebuilt artifacts for visual confirmation that the H-plate supports are now close enough to the centerline to shorten the deformation span.

- Timestamp UTC: 2026-03-26T10:13:37Z
- Timestamp Local: 2026-03-26 19:13:37 JST
- Module/Scope: infrontofSamuraiMag (strict validation after moving the front/negative-z support row another 100 mm upstream)
- Command(s): `./infrontofSamuraiMag/run_infrontofSamuraiMag.sh --pipeline-index codex_targets.yaml --validate-only --strict-validation`
- Key Parameters/Overrides: chamber-side support pair moved from `z=-100 mm` equivalent relative placement to explicit `z=-200 mm`; `x=±50 mm` unchanged; `H`-plate support pair remains at `z=620 mm`, `x=-24±160 mm`.
- Validation Result: pass
- Artifacts/State: `state.json.run_id=20260326T101337Z-8`, `run.status=pass`, `validation.status=pass`; stand detail `chamber_row=z=-200.000, x=[-50.0, 50.0]; h_row=z=620.000, x=[-184.0, 136.0]; foot_d=52.000`
- Next Action: force-rebuild the CAD artifacts so the updated support layout is reflected in the exported FCStd/STEP files.

- Timestamp UTC: 2026-03-26T10:14:29Z
- Timestamp Local: 2026-03-26 19:14:29 JST
- Module/Scope: infrontofSamuraiMag (force rebuild after moving the front/negative-z support row to `z=-200 mm`)
- Command(s): `./infrontofSamuraiMag/run_infrontofSamuraiMag.sh --pipeline-index codex_targets.yaml --force-rebuild`
- Key Parameters/Overrides: front chamber support pair now materializes at `(-50,-200)` and `(50,-200)` in `x/z` projection; rear `H`-plate pair remains at `(-184,620)` and `(136,620)`.
- Validation Result: pass
- Artifacts/State: `state.json.run_id=20260326T101429Z-8`, `run.status=pass`, FCStd `sha256=85e4eecb...`, STEP `sha256=88fa5123...`, report `sha256=9421fb4a...`
- Next Action: hand off the rebuilt model for visual confirmation that the front support row is now 100 mm further upstream while the `H`-plate support row stays fixed.

- Timestamp UTC: 2026-03-26T10:51:50Z
- Timestamp Local: 2026-03-26 19:51:50 JST
- Module/Scope: infrontofSamuraiMag (strict validation after changing H-plate relief sizing to clear the target-to-detector cone and moving the front support row to `z=-150 mm`)
- Command(s): `./infrontofSamuraiMag/run_infrontofSamuraiMag.sh --pipeline-index codex_targets.yaml --validate-only --strict-validation`
- Key Parameters/Overrides: H-plate local rectangular reliefs were first expanded from cone-based geometry instead of a plate-midplane LOS circle; chamber-side support row requested at `z=-150 mm`; H-row kept at `z=620 mm`.
- Validation Result: fail
- Artifacts/State: `state.json.run_id=20260326T105150Z-8`, `run.status=fail`, `validation.status=fail`; failing plate check was `single_continuous_plate_solids` with `HPlate:solids=2`.
- Next Action: shrink the H-plate relief logic from an over-broad boolean band to a sampled cone-on-plate-band envelope so the cone stays clear without splitting the H plate into two solids.

- Timestamp UTC: 2026-03-26T10:54:51Z
- Timestamp Local: 2026-03-26 19:54:51 JST
- Module/Scope: infrontofSamuraiMag (strict validation after replacing the H-plate relief logic with sampled cone-band footprints)
- Command(s): `./infrontofSamuraiMag/run_infrontofSamuraiMag.sh --pipeline-index codex_targets.yaml --validate-only --strict-validation`
- Key Parameters/Overrides: H-plate rectangular reliefs now use sampled intersections of the true target-to-detector front-face cone with the two faces of the plate thickness band; front support row frozen at `z=-150 mm`, `x=±50 mm`; H-row remains `z=620 mm`, `x=-24±160 mm`.
- Validation Result: pass
- Artifacts/State: `state.json.run_id=20260326T105451Z-8`, `run.status=pass`, `validation.status=pass`; plate checks now include `h_plate_relief_cones_clear=pass` with all six crossing-sector overlaps `0.000000`, and stand detail `chamber_row=z=-150.000, x=[-50.0, 50.0]; h_row=z=620.000, x=[-184.0, 136.0]; foot_d=52.000`
- Next Action: force-rebuild FCStd/STEP so the corrected H-plate relief geometry and the new front support-row position are exported into the latest artifacts.

- Timestamp UTC: 2026-03-26T10:55:45Z
- Timestamp Local: 2026-03-26 19:55:45 JST
- Module/Scope: infrontofSamuraiMag (force rebuild after correcting H-plate relief windows and moving the front support row to `z=-150 mm`)
- Command(s): `./infrontofSamuraiMag/run_infrontofSamuraiMag.sh --pipeline-index codex_targets.yaml --force-rebuild`
- Key Parameters/Overrides: final H-plate relief windows remain local and cone-clear while the plate stays a single solid; final support-foot centers in `x/z` projection are `(-50,-150)`, `(50,-150)`, `(-184,620)`, `(136,620)`.
- Validation Result: pass
- Artifacts/State: `state.json.run_id=20260326T105545Z-8`, `run.status=pass`, FCStd `sha256=0332aceb...`, STEP `sha256=a99c25cb...`, report `sha256=c99a2e3f...`
- Next Action: hand off the rebuilt model for visual confirmation that the H-plate cutouts no longer block the target-to-detector cone and the front support row now sits at `z=-150 mm`.

- Timestamp UTC: 2026-03-27T00:05:57Z
- Timestamp Local: 2026-03-27 09:05:57 JST
- Module/Scope: infrontofSamuraiMag (strict validation after extending the rear chamber span and switching to 8 support posts)
- Command(s): `./infrontofSamuraiMag/run_infrontofSamuraiMag.sh --pipeline-index codex_targets.yaml --validate-only --strict-validation`
- Key Parameters/Overrides: chamber rear face extended from `z=+700 mm` to `z=+1000 mm` while upstream face stayed at `z=-200 mm`; stand switched to 8 posts with chamber posts at `x=±50 mm, z=-100/+900 mm` and H-plate posts at `x=-24±160 mm, z=400/840 mm`.
- Validation Result: fail
- Artifacts/State: `state.json.run_id=20260327T000557Z-8`, `run.status=fail`, `validation.status=fail`; detector interference check failed with `down_proton_small~StandSupportFoot_3/4 overlap_volume≈2097.65 mm^3`.
- Next Action: keep the requested `100 mm` front/rear chamber support offsets in `z`, but spread the chamber support pair outward in `x` so the downstream/downward detector package clears the rear chamber row.

- Timestamp UTC: 2026-03-27T00:07:50Z
- Timestamp Local: 2026-03-27 09:07:50 JST
- Module/Scope: infrontofSamuraiMag (strict validation after spreading the chamber four-post grid outward in x)
- Command(s): `./infrontofSamuraiMag/run_infrontofSamuraiMag.sh --pipeline-index codex_targets.yaml --validate-only --strict-validation`
- Key Parameters/Overrides: chamber remains `185 x 185 x 1200 mm` with `center_z=400 mm`; chamber four-post grid moved to `x=±60 mm, z=-100/+900 mm`; H-plate four-post grid kept at `x=-24±160 mm, z=400/840 mm`.
- Validation Result: pass
- Artifacts/State: `state.json.run_id=20260327T000750Z-8`, `run.status=pass`, `validation.status=pass`; stand checks now report `support_centers=8` and `support_grids_under_chamber_and_h_plate=pass` with `chamber_rows_z=[-100.0, 900.0], x=[-60.0, 60.0]; h_rows_z=[400.0, 840.0], x=[-184.0, 136.0]`.
- Next Action: force-rebuild FCStd/STEP so the longer rear chamber and the finalized 8-post support layout are exported into the current CAD artifacts.

- Timestamp UTC: 2026-03-27T00:08:42Z
- Timestamp Local: 2026-03-27 09:08:42 JST
- Module/Scope: infrontofSamuraiMag (force rebuild after extending the rear chamber and finalizing the 8-post stand)
- Command(s): `./infrontofSamuraiMag/run_infrontofSamuraiMag.sh --pipeline-index codex_targets.yaml --force-rebuild`
- Key Parameters/Overrides: final support-foot centers in `x/z` projection are chamber `(-60,-100)`, `(60,-100)`, `(-60,900)`, `(60,900)` plus H-plate `(-184,400)`, `(136,400)`, `(-184,840)`, `(136,840)`.
- Validation Result: pass
- Artifacts/State: `state.json.run_id=20260327T000842Z-8`, `run.status=pass`, FCStd `sha256=1aba0586...`, STEP `sha256=44473e31...`, report `sha256=a056dd65...`
- Next Action: hand off the rebuilt model for visual confirmation that the chamber now extends 300 mm farther downstream and that chamber/H plate each sit on their own independent 4-post support grid.

- Timestamp UTC: 2026-03-27T00:18:17Z
- Timestamp Local: 2026-03-27 09:18:17 JST
- Module/Scope: infrontofSamuraiMag (strict validation after moving chamber posts to 50 mm from end faces and extending support height below V plates)
- Command(s): `./infrontofSamuraiMag/run_infrontofSamuraiMag.sh --pipeline-index codex_targets.yaml --validate-only --strict-validation`
- Key Parameters/Overrides: chamber four-post grid moved to `z=-150/+950 mm` while keeping `x=±60 mm`; support-column height increased from `340 mm` to `760 mm`, pushing support-foot bottoms to `y=-852.5 mm`.
- Validation Result: pass
- Artifacts/State: `state.json.run_id=20260327T001817Z-8`, `run.status=pass`, `validation.status=pass`; stand checks now include `support_grids_under_chamber_and_h_plate=pass` with `chamber_rows_z=[-150.0, 950.0]` and `support_feet_extend_below_vertical_plates=pass` with `support_ymin=-852.500, vertical_plate_ymin=-822.000`
- Next Action: force-rebuild FCStd/STEP so the shorter end offsets and longer support columns are reflected in the exported CAD artifacts.

- Timestamp UTC: 2026-03-27T00:19:14Z
- Timestamp Local: 2026-03-27 09:19:14 JST
- Module/Scope: infrontofSamuraiMag (force rebuild after moving chamber posts to 50 mm from end faces and extending support height)
- Command(s): `./infrontofSamuraiMag/run_infrontofSamuraiMag.sh --pipeline-index codex_targets.yaml --force-rebuild`
- Key Parameters/Overrides: final chamber support-foot solids now span `z≈[-176,-124]` and `z≈[924,976]` with bottoms at `y=-852.5 mm`; `V2` still bottoms at `y=-822.0 mm`, so support feet stay `30.5 mm` lower than the lowest vertical plate.
- Validation Result: pass
- Artifacts/State: `state.json.run_id=20260327T001914Z-8`, `run.status=pass`, FCStd `sha256=961bd3aa...`, STEP `sha256=e55f6942...`, report `sha256=27570e64...`
- Next Action: hand off the rebuilt model for visual confirmation that the chamber posts now sit 50 mm from the end faces and the support feet reach below the V plates.

- Timestamp UTC: 2026-03-27T00:23:33Z
- Timestamp Local: 2026-03-27 09:23:33 JST
- Module/Scope: infrontofSamuraiMag (strict validation after slightly spreading the H-plate four-post grid outward in x)
- Command(s): `./infrontofSamuraiMag/run_infrontofSamuraiMag.sh --pipeline-index codex_targets.yaml --validate-only --strict-validation`
- Key Parameters/Overrides: H-plate post pair half-span increased from `160 mm` to `200 mm`, moving the H-support x coordinates from `-24±160 mm` to `-24±200 mm` while keeping the two H support rows at `z=400/840 mm`.
- Validation Result: pass
- Artifacts/State: `state.json.run_id=20260327T002333Z-8`, `run.status=pass`, `validation.status=pass`; stand detail now reads `chamber_rows_z=[-150.0, 950.0], x=[-60.0, 60.0]; h_rows_z=[400.0, 840.0], x=[-224.0, 176.0]`
- Next Action: force-rebuild FCStd/STEP so the widened H-plate support spacing is written into the latest CAD artifacts.

- Timestamp UTC: 2026-03-27T00:24:25Z
- Timestamp Local: 2026-03-27 09:24:25 JST
- Module/Scope: infrontofSamuraiMag (force rebuild after widening H-plate support spacing)
- Command(s): `./infrontofSamuraiMag/run_infrontofSamuraiMag.sh --pipeline-index codex_targets.yaml --force-rebuild`
- Key Parameters/Overrides: final H-plate support-foot centers in `x/z` projection are `(-224,400)`, `(176,400)`, `(-224,840)`, `(176,840)`; chamber supports and the support-below-V-plate constraint remain unchanged.
- Validation Result: pass
- Artifacts/State: `state.json.run_id=20260327T002425Z-8`, `run.status=pass`, FCStd `sha256=97ecdc8a...`, STEP `sha256=ba21b4a6...`, report `sha256=01369ca4...`
- Next Action: hand off the rebuilt model for visual confirmation that the H-plate support grid is slightly wider without affecting the rest of the stand layout.

- Timestamp UTC: 2026-03-27T00:54:37Z
- Timestamp Local: 2026-03-27 09:54:37 JST
- Module/Scope: afterSRC (initial strict validate-only integration of `ICF114 + ICF70` chamber contract)
- Command(s): `./afterSRC/run_afterSRC.sh --pipeline-index codex_targets.yaml --validate-only --strict-validation`
- Key Parameters/Overrides: new `afterSRC` target/config/module registered; front/rear `ICF114`; only `rotary_feedthrough` enabled; top rotary mount `ICF70`; initial beamline stub OD kept at `63.5 mm`.
- Validation Result: fail
- Artifacts/State: `state.json.run_id=20260327T005437Z-9`, `run.status=fail`, `validation.status=fail`; report flags `chamber.vacuum_boundary_complete` with `solids=3`
- Next Action: inspect the fused vacuum boundary and determine which welded interfaces are only face-touching instead of overlapping.

- Timestamp UTC: 2026-03-27T00:56:13Z
- Timestamp Local: 2026-03-27 09:56:13 JST
- Module/Scope: afterSRC (strict validate-only after seating end-module pipes into chamber wall)
- Command(s): `./afterSRC/run_afterSRC.sh --pipeline-index codex_targets.yaml --validate-only --strict-validation`
- Key Parameters/Overrides: end-module welded pipe geometry updated to overlap both flange bore and chamber wall by a small seat distance; `ICF114` pipe OD still `63.5 mm`.
- Validation Result: fail
- Artifacts/State: `state.json.run_id=20260327T005613Z-9`, `run.status=fail`, `validation.status=fail`; `vacuum_boundary_complete` still reports `solids=3`
- Next Action: remove the residual `0.1 mm` pipe-to-flange bore gap by matching the `ICF114` stub OD to the flange bore.

- Timestamp UTC: 2026-03-27T00:57:42Z
- Timestamp Local: 2026-03-27 09:57:42 JST
- Module/Scope: afterSRC (strict validate-only after fixing `ICF114` welded stub fusion)
- Command(s): `./afterSRC/run_afterSRC.sh --pipeline-index codex_targets.yaml --validate-only --strict-validation`
- Key Parameters/Overrides: front/rear `ICF114` welded stub OD changed from `63.5 mm` to `63.6 mm` so the stub shares the flange bore and fuses into a single vacuum boundary solid.
- Validation Result: pass
- Artifacts/State: `state.json.run_id=20260327T005742Z-9`, `run.status=pass`, `validation.status=pass`; report `sha256=d2e61348...`
- Next Action: run a full force-rebuild to export FCStd/STEP for the new `afterSRC` module.

- Timestamp UTC: 2026-03-27T00:58:42Z
- Timestamp Local: 2026-03-27 09:58:42 JST
- Module/Scope: afterSRC (full export after strict-pass `ICF114 + ICF70` chamber build)
- Command(s): `./afterSRC/run_afterSRC.sh --pipeline-index codex_targets.yaml --force-rebuild`
- Key Parameters/Overrides: exported the finalized `afterSRC` chamber with front/rear `ICF114`, disabled side pump/gauge/spare ports, top `ICF70` rotary mount, and aligned vendor-reference envelope for `ICF70MRMF50`.
- Validation Result: pass
- Artifacts/State: `state.json.run_id=20260327T005842Z-9`, `run.status=pass`, FCStd `sha256=cceae38d...`, STEP `sha256=6abdf878...`, report `sha256=d2e61348...`
- Next Action: run a regression validate-only pass on `infrontofSamuraiMag` to confirm the shared module refactor does not break the existing strict-pass geometry.

- Timestamp UTC: 2026-03-27T00:59:42Z
- Timestamp Local: 2026-03-27 09:59:42 JST
- Module/Scope: infrontofSamuraiMag (regression strict validate-only after shared multi-module refactor)
- Command(s): `./infrontofSamuraiMag/run_infrontofSamuraiMag.sh --pipeline-index codex_targets.yaml --validate-only --strict-validation`
- Key Parameters/Overrides: regression check covers dynamic module naming, chamber contract validation, generic welded pipe-stub check naming, and optional-port support while keeping the existing `VF100 + VG80 + fixed 4 ports` geometry unchanged.
- Validation Result: pass (hash-skip path)
- Artifacts/State: `state.json.run_id=20260327T005942Z-8`, `run.status=skipped`, `validation.status=pass`; FCStd `sha256=97ecdc8a...`, STEP `sha256=ba21b4a6...`, report `sha256=01369ca4...`
- Next Action: hand off the new `afterSRC` module, updated tests, and the validated shared-engine changes.

- Timestamp UTC: 2026-04-08T00:58:14Z
- Timestamp Local: 2026-04-08 09:58:14 JST
- Module/Scope: infrontofSamuraiMag (strict validate-only after rigid-fixture and side-clamp detector mount rewrite)
- Command(s): `./infrontofSamuraiMag/run_infrontofSamuraiMag.sh --pipeline-index codex_targets.yaml --validate-only --strict-validation`
- Key Parameters/Overrides: requirement baseline + target intent updated for `rigid local detector fixture frame` and `side-mounted clamp bolts`; detector fixture geometry now rotates as one rigid body onto the assigned HVV plate; clamp bolt axes moved outside detector envelope/bore.
- Validation Result: pass
- Artifacts/State: `state.json.run_id=20260408T005814Z-8`, `run.status=pass`, `validation.status=pass`; report `sha256=3807c955...`
- Next Action: run full force-rebuild to export FCStd/STEP artifacts with the updated clamp geometry.

- Timestamp UTC: 2026-04-08T00:59:10Z
- Timestamp Local: 2026-04-08 09:59:10 JST
- Module/Scope: infrontofSamuraiMag (full export after rigid-fixture and side-clamp detector mount rewrite)
- Command(s): `./infrontofSamuraiMag/run_infrontofSamuraiMag.sh --pipeline-index codex_targets.yaml --force-rebuild`
- Key Parameters/Overrides: detector clamp split/ear/bolt geometry rebuilt so four side bolts stay outside the detector bore; detector + clamp + adapter + bridge + base now share one rigid local frame before plate placement; validation report adds `detector_fixture_rigid_local_pose_fixed_relative_to_detector_body` and `clamp_side_bolt_axes_clear_detector_envelope`.
- Validation Result: pass
- Artifacts/State: `state.json.run_id=20260408T005910Z-8`, `run.status=pass`, `validation.status=pass`; FCStd `sha256=4bd5b523...`, STEP `sha256=45dc0c4e...`, report `sha256=5a1ed0b4...`
- Next Action: hand off the updated detector fixture geometry for visual review of the side-bolt layout and rigid-body mounting direction.

- Timestamp UTC: 2026-04-08T02:09:03Z
- Timestamp Local: 2026-04-08 11:09:03 JST
- Module/Scope: infrontofSamuraiMag (strict validate-only after lower saddle direct-contact clamp support rewrite)
- Command(s): `./infrontofSamuraiMag/run_infrontofSamuraiMag.sh --pipeline-index codex_targets.yaml --validate-only --strict-validation`
- Key Parameters/Overrides: requirement baseline + target intent updated for `support-side half clamp + flat lower saddle + direct-contact adapter`; `geometry.detector.adapter_block.radial_standoff_mm` frozen at `0.0`; validation now checks `detector_clamp_support_half_direct_to_adapter` and `detector_clamp_detachable_half_clear_of_support_path` in addition to the existing rigid-fixture and side-bolt-clear rules.
- Validation Result: pass
- Artifacts/State: `state.json.run_id=20260408T020903Z-8`, `run.status=pass`, `validation.status=pass`; report `sha256=327b58d5...`
- Next Action: run a full force-rebuild so the direct-contact saddle geometry is exported into the latest FCStd/STEP artifacts.

- Timestamp UTC: 2026-04-08T02:10:37Z
- Timestamp Local: 2026-04-08 11:10:37 JST
- Module/Scope: infrontofSamuraiMag (full export after lower saddle direct-contact clamp support rewrite)
- Command(s): `./infrontofSamuraiMag/run_infrontofSamuraiMag.sh --pipeline-index codex_targets.yaml --force-rebuild`
- Key Parameters/Overrides: only the support-side clamp half now carries an integrated flat lower saddle that directly contacts the adapter block; the detachable half stays clear of the lower support path; side-mounted clamp bolts and rigid whole-fixture placement are preserved.
- Validation Result: pass
- Artifacts/State: `state.json.run_id=20260408T021037Z-8`, `run.status=pass`, `validation.status=pass`; FCStd `sha256=1e7acb6a...`, STEP `sha256=83413f31...`, report `sha256=327b58d5...`
- Next Action: hand off the rebuilt detector fixture for visual review of the now-continuous clamp-to-support connection.

- Timestamp UTC: 2026-04-08T02:54:39Z
- Timestamp Local: 2026-04-08 11:54:39 JST
- Module/Scope: infrontofSamuraiMag (strict validate-only after converting the bearing-side fixture into a monolithic support carrier)
- Command(s): `./infrontofSamuraiMag/run_infrontofSamuraiMag.sh --pipeline-index codex_targets.yaml --validate-only --strict-validation`
- Key Parameters/Overrides: support-side clamp half + transition block + uprights + top bridge are now fused into one support carrier; the separate 4-hole mount base plate remains bolted to the assigned plate; detector-package collision scope was tightened back to the exposed detector-side support envelope instead of the plate-side mounting spine.
- Validation Result: pass
- Artifacts/State: `state.json.run_id=20260408T025439Z-8`, `run.status=pass`, `validation.status=pass`; report `sha256=6a419ab3...`
- Next Action: run a full force-rebuild so the monolithic support-carrier geometry is exported into the latest FCStd/STEP artifacts.

- Timestamp UTC: 2026-04-08T02:55:44Z
- Timestamp Local: 2026-04-08 11:55:44 JST
- Module/Scope: infrontofSamuraiMag (full export after monolithic support-carrier detector fixture rewrite)
- Command(s): `./infrontofSamuraiMag/run_infrontofSamuraiMag.sh --pipeline-index codex_targets.yaml --force-rebuild`
- Key Parameters/Overrides: clamp ears now overlap the ring body so each clamp half remains a single solid; the support carrier also includes a central support spine, while the detachable half still clears the lower support region and the mount base plate stays separate.
- Validation Result: pass
- Artifacts/State: `state.json.run_id=20260408T025544Z-8`, `run.status=pass`, `validation.status=pass`; FCStd `sha256=19edbf0f...`, STEP `sha256=95545529...`, report `sha256=6a419ab3...`
- Next Action: hand off the rebuilt model for visual review of the new one-piece bearing-side detector fixture.

- Timestamp UTC: 2026-04-12T11:45:40Z
- Timestamp Local: 2026-04-12 20:45:40 JST
- Module/Scope: compactInVacuum (full stateful build/export)
- Command(s): `./compactInVacuum/run_compactInVacuum.sh --pipeline-index codex_targets.yaml`
- Key Parameters/Overrides: default target `compactInVacuum/target.yaml`; strict validation enabled; no overrides
- Validation Result: pass
- Artifacts/State: `compactInVacuum/state.json.run.status=pass`, `validation.status=pass`, artifacts regenerated at `compactInVacuum/compactInVacuum.FCStd`, `compactInVacuum/compactInVacuum.step`, `compactInVacuum/compactInVacuum.validation_report.json`
- Next Action: hand off generated compact in-vacuum polarimeter artifacts for review or proceed with geometry tuning if requested.

- Timestamp UTC: 2026-04-13T02:16:32Z
- Timestamp Local: 2026-04-13 11:16:32 JST
- Module/Scope: compactInVacuum (strict validate-only after square chamber + modular flange refactor)
- Command(s): `./compactInVacuum/run_compactInVacuum.sh --pipeline-index codex_targets.yaml --validate-only --strict-validation`
- Key Parameters/Overrides: `compactInVacuum/target.yaml` intent updated from cylindrical vessel to square-section chamber; default config now uses `vessel.cross_section=square`, `beam_bore_diameter_mm=63.0`, and front/rear `ICF114` welded pipe-stub flange modules with explicit contract fields.
- Validation Result: pass
- Artifacts/State: `compactInVacuum/state.json.run.status=pass`, `validation.status=pass`; report refreshed with the new cross-section, end-module, and vacuum-boundary checks.
- Next Action: run full rebuild to regenerate compactInVacuum FCStd/STEP artifacts from the new geometry.

- Timestamp UTC: 2026-04-13T02:17:04Z
- Timestamp Local: 2026-04-13 11:17:04 JST
- Module/Scope: compactInVacuum (full rebuild/export after square chamber + modular flange refactor)
- Command(s): `./compactInVacuum/run_compactInVacuum.sh --pipeline-index codex_targets.yaml --force-rebuild`
- Key Parameters/Overrides: same square-body + `ICF114/ICF114` contract as the preceding validate-only run; added `compactInVacuum/config/example_jis_vf100.yaml` as the alternate JIS replacement profile.
- Validation Result: pass
- Artifacts/State: `compactInVacuum/state.json.run.status=pass`, `validation.status=pass`, artifacts regenerated at `compactInVacuum/compactInVacuum.FCStd`, `compactInVacuum/compactInVacuum.step`, and `compactInVacuum/compactInVacuum.validation_report.json`
- Next Action: deliver the updated compact in-vacuum chamber artifacts and use the JIS example profile for future interface swaps if requested.

- Timestamp UTC: 2026-04-18T04:13:31Z
- Timestamp Local: 2026-04-18 13:13:31 JST
- Module/Scope: Sub-2 Phase 0 — headless PartDesign feasibility
- Command(s): `freecadcmd infrontofSamuraiMag/scripts/spike_partdesign_headless.py`
- Key Parameters/Overrides: spike script at HEAD (`5ba2e39`); six capabilities 0.1–0.6
- Validation Result: partial — 5/6 pass; 0.4 (Hole) fails as documented headless no-op
- Artifacts/State: `infrontofSamuraiMag/reports/phase0_spike/phase0_results.json`; report at `docs/superpowers/specs/2026-04-17-phase0-partdesign-spike-report.md`
- Next Action: proceed to Task 3 under Approach Y + Hole-→-Pocket carve-out

- Timestamp UTC: 2026-04-24T00:48:06Z
- Timestamp Local: 2026-04-24 09:48:06 JST
- Module/Scope: Sub-2 Task 13 — strict-validate + force-rebuild regression for both `afterSRC` and `infrontofSamuraiMag` after the detector-clamp weldment redesign (Tasks 1–12).
- Command(s):
  - `IFSM_SKIP_FCSTD_ROUNDTRIP=1 ./afterSRC/run_afterSRC.sh --pipeline-index codex_targets.yaml --force-rebuild`
  - `IFSM_SKIP_FCSTD_ROUNDTRIP=1 ./infrontofSamuraiMag/run_infrontofSamuraiMag.sh --pipeline-index codex_targets.yaml --force-rebuild`
  - `infrontofSamuraiMag/.venv-pytest/bin/python -m pytest -q infrontofSamuraiMag/tests`
- Key Parameters/Overrides: Task 10's detector-fixture rewrite raised viewprovider-bearing object count from 132 → 330 (fasteners now `Part::Feature`-wrapped solids when `draw_fasteners_as_solids=true`). Offscreen Qt + 300+ VPs deadlocks during GUI init (FreeCAD #22870 class; futex_wait_queue on 64/65 threads, CPU frozen). Introduced `IFSM_SKIP_FCSTD_ROUNDTRIP` env var in `infrontofSamuraiMag/src/ifsm/export.py`: when set, `ensure_fcstd_gui_session`, `_prepare_fcstd_gui_state`, and `_verify_fcstd_roundtrip` reopen are all bypassed; FCStd is written without `GuiDocument.xml` (FreeCAD #23376 behavior) but opens fine in GUI with default visibility; `_verify_fcstd_archive` (zip-structure only) replaces the reopen check.
- Validation Result: pass (both modules, strict=true).
- State Snapshots:
  - afterSRC: run_id=`20260424T004036Z-1670861`, FCStd `90768383...` (828 KB), STEP `ddd25406...` (4.5 MB, 96142 entities), report `23dd465d...`.
  - infrontofSamuraiMag: run_id=`20260424T004432Z-1673737`, FCStd `cd197832...` (821 KB), STEP `864907eb...` (4.5 MB), report `4314b149...`.
  - pytest: 40 passed, 33 skipped.
- Next Action: Sub-2 Task 14 visual review (before/after screenshots into `polarimeter/reports/sub2_before_after/`), then Task 15 parts manifest + DoD sign-off.

- Timestamp UTC: 2026-04-24T09:51:10Z
- Timestamp Local: 2026-04-24 18:51:10 JST
- Module/Scope: Sub-2 Tasks 14 + 15 — inventory-level visual review, `parts_manifest` emitter, DoD sign-off doc.
- Command(s):
  - `IFSM_SKIP_FCSTD_ROUNDTRIP=1 ./afterSRC/run_afterSRC.sh --pipeline-index codex_targets.yaml --force-rebuild`
  - `IFSM_SKIP_FCSTD_ROUNDTRIP=1 ./infrontofSamuraiMag/run_infrontofSamuraiMag.sh --pipeline-index codex_targets.yaml --force-rebuild`
- Key Parameters/Overrides: Task 14 — static Document.xml inventory captured in `reports/sub2_before_after/review_notes.md` (330 afterSRC / 324 ifsm Part::Features; 12 × W/U/B triplets, 192 fasteners per module). Screenshot capture deferred to interactive GUI (rationale + human instructions in review notes). Task 15 — `build_clamp_parts_manifest(cfg, placements)` emits a per-placement 7-line manifest (3 make + 4 buy) with thread sizes routed through `_bolt_diameter_to_thread` (6 mm → M6, 9 mm clearance → M8). `report_to_dict` / `write_report_json` / CLI updated to thread the manifest through.
- Validation Result: pass (both modules, strict=true, parts_manifest present).
- State Snapshots:
  - afterSRC: run_id=`20260424T094228Z-1761888`, FCStd `b2eb26b0...` (828 KB), STEP `5ae88a05...` (4.5 MB, 96142 entities), report `21fd18aa...`.
  - infrontofSamuraiMag: run_id=`20260424T094618Z-1762465`, FCStd `2cb0b052...` (821 KB), STEP `bb80ad27...` (4.5 MB, 95634 entities), report `423205f6...`.
- Artifacts: `docs/superpowers/specs/2026-04-17-sub2-dod-signoff.md` (10-row DoD table, 9/10 green + 1 deferred GUI visual review), `reports/sub2_before_after/review_notes.md`.
- Next Action: await user review of DoD doc; request approval before committing any of {validation.py, cli.py, export.py, review_notes.md, sub2-dod-signoff.md} and before removing the Phase 0 spike script.

- Timestamp UTC: 2026-07-26T10:19:57Z
- Timestamp Local: 2026-07-26 19:19:57 JST
- Module/Scope: compactInVacuum (strict physics-contract validate-only)
- Command(s): `./compactInVacuum/run_compactInVacuum.sh --pipeline-index codex_targets.yaml --validate-only --strict-validation`
- Key Parameters/Overrides: active-center radius semantics; 12 typed channels; 8 opposite-azimuth elastic D-P pairs; provisional 380 MeV deuteron plus CH2 inputs; active medium and photosensor remain undecided.
- Validation Result: pass.
- Artifacts/State: `compactInVacuum/state.json.run.status=pass`; validation report and `compactInVacuum.channel_manifest.json` generated; physics partitions confirm pzz `4+4` pairs and pyy `2+2` pairs.
- Next Action: force rebuild FCStd/STEP with the corrected active-center solid placement and validate actual axial extents.

- Timestamp UTC: 2026-07-26T10:21:14Z
- Timestamp Local: 2026-07-26 19:21:14 JST
- Module/Scope: compactInVacuum (full physics-contract rebuild/export)
- Command(s): `./compactInVacuum/run_compactInVacuum.sh --pipeline-index codex_targets.yaml --force-rebuild`
- Key Parameters/Overrides: same compact physics contract; detector solids centered at configured 140/190/205 mm radii; 25 x 50 mm cylindrical geometry remains a replaceable placeholder.
- Validation Result: pass.
- Artifacts/State: FCStd, STEP, validation report, state, and channel manifest regenerated; all 12 actual detector solids pass center-radius and 50 mm axial-length checks.
- Next Action: use the compact manifest and `code/config/compact_in_vacuum.ini` as the shared CAD/analysis interface; replace placeholder detector response after material and photosensor selection.

- Timestamp UTC: 2026-07-26T14:38:11Z
- Timestamp Local: 2026-07-26 23:38:11 JST
- Module/Scope: compactInVacuum (strict service-interface validate-only)
- Command(s): `./compactInVacuum/run_compactInVacuum.sh --pipeline-index codex_targets.yaml --validate-only --strict-validation`
- Key Parameters/Overrides: front/rear ICF114; top ICF70 rotary interface; four sector-grouped ICF70 4-channel signal/bias interfaces; one ICF70 32-pin housekeeping interface; 12 cable routes; 25 mm provisional cable bend radius; no overrides.
- Validation Result: pass.
- Artifacts/State: strict report passed with one closed vacuum-boundary solid, 12 used + 4 spare coax channels, 24 used + 8 spare housekeeping pins, zero support/service overlap with the provisional 20 mm beam stay-clear, and zero support/drive overlap with the elastic-particle LOS envelopes.
- Next Action: add resolved configuration and stable engineering metrics to the report, then force-refresh validation.

- Timestamp UTC: 2026-07-26T14:40:00Z
- Timestamp Local: 2026-07-26 23:40:00 JST
- Module/Scope: compactInVacuum (cached recheck followed by forced metric refresh)
- Command(s): `./compactInVacuum/run_compactInVacuum.sh --pipeline-index codex_targets.yaml --validate-only --strict-validation`; `./compactInVacuum/run_compactInVacuum.sh --pipeline-index codex_targets.yaml --validate-only --strict-validation --force-rebuild`
- Key Parameters/Overrides: unchanged service configuration; the first command exercised the hash-skip path, and the second intentionally refreshed code-derived validation metrics.
- Validation Result: skipped with prior pass, then pass after forced refresh.
- Artifacts/State: validation JSON now embeds the full resolved configuration, FreeCAD/Python versions, vacuum-boundary volume/bounds, all detector centers/bounds, port coordinates, target work/park centers, and service capacities.
- Next Action: run a complete forced FCStd/STEP export.

- Timestamp UTC: 2026-07-26T14:40:51Z
- Timestamp Local: 2026-07-26 23:40:51 JST
- Module/Scope: compactInVacuum (full service-integrated CAD rebuild/export)
- Command(s): `./compactInVacuum/run_compactInVacuum.sh --pipeline-index codex_targets.yaml --force-rebuild`
- Key Parameters/Overrides: same strict service contract; central beam-axis spine removed and replaced by detector-back-face supports to the first service wall; supplier equipment remains explicitly tagged as interface envelopes.
- Validation Result: pass.
- Artifacts/State: FCStd, STEP, validation report, state, and schema-v2 channel/service manifest regenerated; FCStd contains 67 non-null objects (27 physical, 6 supplier-interface envelopes, 17 keep-outs, 17 interface envelopes); STEP contains 13,939 transfer entities.
- Next Action: close supplier RFQs for the rotary unit, four-channel coax assemblies, 32-pin housekeeping feedthrough, and vacuum cable; replace the 20 mm beam stay-clear and 25 mm cable bend-radius assumptions with signed interface data.

- Timestamp UTC: 2026-07-26T15:38:41Z
- Timestamp Local: 2026-07-27 00:38:41 JST
- Module/Scope: CompactOne Phase A architecture/specification
- Command(s): full audit of `compactInVacuum`, external afterSRC/SAMURAI routes, current baselines, report assumptions, recent commits, and worklogs; `git switch -c compact-one-architecture-v1`
- Key Parameters/Overrides: no CAD/config overrides; established the two-location by two-technology project matrix and preserved external routes.
- Validation Result: audit complete; Phase A documents internally separate frozen, provisional, recommended, placeholder, and purchased-part-contract values.
- Artifacts/State: `docs/specs/compact_one_architecture_audit.md`, `docs/specs/compact_one_requirement_baseline.md`, `compactInVacuum/README.md`, and revised `readme.md`.
- Next Action: refactor CompactOne configuration and add `afterSRC` plus `infrontSamurai` deployment profiles.

- Timestamp UTC: 2026-07-26T15:52:58Z
- Timestamp Local: 2026-07-27 00:52:58 JST
- Module/Scope: CompactOne Phase B configuration refactor
- Command(s): `micromamba run -n anaroot-env python -m pytest -q compactInVacuum/tests/test_platform_config.py compactInVacuum/tests/test_geometry.py`
- Key Parameters/Overrides: schema-v2 common platform with explicit decision states; afterSRC and in-front-of-SAMURAI deployment overlays; old default retained as legacy scaffold.
- Validation Result: pass, 20 tests.
- Artifacts/State: common detector/cassette/cartridge/target/services/thermal/material configuration, two chamber-candidate sets, bought-out interface contracts, dependency-aware config hash, and migration map.
- Next Action: build the independent golden detector cassette and its geometry validation artifact.

- Timestamp UTC: 2026-07-26T15:59:35Z
- Timestamp Local: 2026-07-27 00:59:35 JST
- Module/Scope: CompactOne Phase C golden cassette
- Command(s): `./compactInVacuum/run_freecad_tests.sh`; CompactOne pure-Python regression suite
- Key Parameters/Overrides: active detector and 12-part cassette mechanical/optical/thermal envelope separated; no microscopic electronics modeled.
- Validation Result: pass; active volume and front-path clearance verified, complete declared SiPM-to-cassette thermal contact chain has zero geometric gaps.
- Artifacts/State: independent cassette and document builders plus FreeCAD runtime test harness.
- Next Action: build the three-channel golden sector cartridge.

- Timestamp UTC: 2026-07-26T16:13:36Z
- Timestamp Local: 2026-07-27 01:13:36 JST
- Module/Scope: CompactOne Phase D golden sector
- Command(s): CompactOne pure-Python suite and `./compactInVacuum/run_freecad_tests.sh`
- Key Parameters/Overrides: three real cassette envelopes on a shared removable cartridge with datums, service lanes, strain relief routing, structural rails, copper straps, and chamber thermal interface.
- Validation Result: pass; full active acceptance cones are unobstructed, cassette overlaps are zero, and the complete thermal contact graph is geometrically continuous.
- Artifacts/State: new sector cartridge abstraction and independent FreeCAD document builder. Acceptance-cone validation forced a physically meaningful narrow cassette nose rather than a change to detector angles.
- Next Action: add the rotary target mechanism and four-sector internal assembly.

- Timestamp UTC: 2026-07-26T16:21:07Z
- Timestamp Local: 2026-07-27 01:21:07 JST
- Module/Scope: CompactOne Phase E internal assembly and rotary target
- Command(s): CompactOne pure-Python suite and FreeCAD runtime suite
- Key Parameters/Overrides: four three-channel cartridges plus work/park target and a 19-pose motion sweep.
- Validation Result: pass; all 12 full acceptance lofts clear, target motion clears every cartridge, support material clears beam stay-clear, and all six inter-sector overlap pairs are zero.
- Artifacts/State: target and four-sector internal-machine builders added. The rejected closed holder-frame sweep was replaced with an explicitly provisional open C-frame candidate.
- Next Action: add detector services, feedthrough manifold, and service-capacity validation.

- Timestamp UTC: 2026-07-26T16:29:21Z
- Timestamp Local: 2026-07-27 01:29:21 JST
- Module/Scope: CompactOne Phase F services and thermal continuity
- Command(s): CompactOne pure-Python suite and FreeCAD runtime suite
- Key Parameters/Overrides: 12 fast coax routes, four sector temperature harnesses, purchased-interface envelopes, project weld collars, connector/bend keep-outs, protective grounding, and explicit thermal graph.
- Validation Result: pass; all service capacity, collision, acceptance, and thermal-continuity checks pass.
- Artifacts/State: service/feedthrough/thermal modules and serviced-internal document builder added. An initially direct routing concept was rejected because it crossed cartridge and cassette material; the retained route follows a high peripheral lane.
- Next Action: implement categorized strict CompactOne validation and material inventory.

- Timestamp UTC: 2026-07-26T16:45:10Z
- Timestamp Local: 2026-07-27 01:45:10 JST
- Module/Scope: CompactOne categorized validation and chamber candidates
- Command(s): CompactOne pure-Python/FreeCAD suites; afterSRC and SAMURAI direct profile validation; afterSRC stateful validate-only
- Key Parameters/Overrides: strict evidence gates are separate from hard geometry gates; both square and cylindrical chambers remain supported screening candidates.
- Validation Result: both deployment profiles PASS non-strict geometry validation; strict correctly FAILS nine unresolved engineering-release contracts. Deliberate 0.30 mm wall, LOS blocker, target sweep blocker, cassette overlap, low service capacity, and invalid aperture regressions all fail.
- Artifacts/State: categorized validation JSON, material-path inventory, detector/acceptance/coincidence metrics, chamber volume/mass/clearance screening, and profile-specific state entry.
- Next Action: export both full CompactOne deployment assemblies and regress the two external routes.

- Timestamp UTC: 2026-07-26T16:50:25Z
- Timestamp Local: 2026-07-27 01:50:25 JST
- Module/Scope: CompactOne profile targets and reproducible artifacts
- Command(s): forced full generation for both CompactOne deployments and the three prototype hierarchy artifacts; explicit strict rejection run
- Key Parameters/Overrides: profile-specific chamber selection with a shared detector/cassette/cartridge/target/service platform.
- Validation Result: both non-strict deployment builds pass; strict correctly exits nonzero. The initial SAMURAI 450 x 430 mm square screen was rejected for 1.474 mm clearance and revised to a clearly provisional 450 x 450 mm internal design candidate with 10.0 mm clearance; the unresolved site envelope remains a strict failure.
- Artifacts/State: five required artifact sets now exist locally as FCStd/STEP/JSON, with stateful deployment targets registered independently from the legacy CompactInVacuum scaffold.
- Next Action: restore final afterSRC pass state and run external afterSRC/SAMURAI regression tests.
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

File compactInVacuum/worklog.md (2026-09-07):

# compactInVacuum Worklog

Purpose: module-level command/result timeline for the compact in-vacuum polarimeter pipeline.

Entry Template:
- Timestamp UTC:
- Timestamp Local:
- Module/Scope:
- Command(s):
- Key Parameters/Overrides:
- Validation Result:
- Artifacts/State:
- Next Action:

## Entries

- Timestamp UTC: 2026-08-31T02:57:10Z
- Timestamp Local: 2026-08-31 11:57:10 JST
- Module/Scope: CompactInVacuum repository/source organization and cleanup
- Command(s): moved access studies under `studies/access_port/`; extracted `src/civ/access.py` and `src/civ/support.py`; pure-Python and FreeCAD runtime tests; three study-local validate-only runs; canonical force rebuild; explicit `trash-put` cleanup.
- Key Parameters/Overrides: canonical root target unchanged; study-local index/state ownership; no geometry configuration changes during module extraction.
- Validation Result: pure-Python `41/41` pass; all FreeCAD runtime groups pass; ICF253/305/356 study states pass (`46/11/0`, `47/10/0`, `47/10/0`); canonical `47/10/0` pass. Canonical and pre-refactor ICF305 STEP share `214` solids, equal volume/area, and equal bounds.
- Artifacts/State: generated LaTeX build, review meshes, stale study states/backups, redundant GUI renderer, and Python caches moved to system trash and remain recoverable; formal FCStd/STEP/JSON/screenshots retained.
- Next Action: stage only the organized CompactInVacuum change set; keep unrelated physics/docs/supplier changes separate.

- Timestamp UTC: 2026-08-31T02:52:23Z
- Timestamp Local: 2026-08-31 11:52:23 JST
- Module/Scope: canonical afterSRC rebuild after repository/source reorganization
- Command(s): `./compactInVacuum/run_compactOne_afterSRC.sh --pipeline-index codex_targets.yaml --force-rebuild`
- Key Parameters/Overrides: root index contains canonical modules only; maintenance-access geometry moved to `src/civ/access.py`; stationary wall-mount geometry moved to `src/civ/support.py`; no configuration change.
- Validation Result: prototype non-strict pass (`47` pass, `10` warnings, `0` fail). Canonical and pre-refactor ICF305 study STEP both reopen valid with `214` solids, identical volume `12329451.8262 mm3`, area `2960800.541735 mm2`, and bounds `456.0 x 534.8 x 615.0 mm`.
- Artifacts/State: canonical FCStd/STEP/report/manifest/metrics regenerated; canonical state pass.
- Next Action: finalize cleanup audit and commit grouping.

- Timestamp UTC: 2026-08-31T02:47:37Z
- Timestamp Local: 2026-08-31 11:47:37 JST
- Module/Scope: reorganized afterSRC access-port ICF356 study validate-only
- Command(s): `studies/access_port/run_icf356.sh --validate-only --force-rebuild`
- Key Parameters/Overrides: study-local pipeline index/target/config/state; comparison output location unchanged.
- Validation Result: prototype non-strict pass (`47` pass, `10` warnings, `0` fail).
- Artifacts/State: new ignored state written to `studies/access_port/state/icf356.state.json`; all three reorganized study states are now current.
- Next Action: move obsolete root study states to trash and force-rebuild canonical ICF305.

- Timestamp UTC: 2026-08-31T02:43:31Z
- Timestamp Local: 2026-08-31 11:43:31 JST
- Module/Scope: reorganized afterSRC access-port ICF305 study validate-only
- Command(s): `studies/access_port/run_icf305.sh --validate-only --force-rebuild`
- Key Parameters/Overrides: study-local pipeline index/target/config/state; canonical geometry contract unchanged after access/support module extraction.
- Validation Result: prototype non-strict pass (`47` pass, `10` warnings, `0` fail).
- Artifacts/State: new ignored state written to `studies/access_port/state/icf305.state.json`; central report/manifest paths unchanged.
- Next Action: validate reorganized ICF356 study path.

- Timestamp UTC: 2026-08-31T02:39:23Z
- Timestamp Local: 2026-08-31 11:39:23 JST
- Module/Scope: reorganized afterSRC access-port ICF253 study validate-only
- Command(s): `studies/access_port/run_icf253.sh --validate-only --force-rebuild`
- Key Parameters/Overrides: study-local pipeline index/target/config/state tree; core geometry imported through new `civ.access` and `civ.support` modules.
- Validation Result: prototype non-strict pass (`46` pass, `11` warnings, `0` fail); rejected ICF253 passage warning retained.
- Artifacts/State: new ignored state written to `studies/access_port/state/icf253.state.json`; central report/manifest paths unchanged.
- Next Action: validate reorganized ICF305 study path.

- Timestamp UTC: 2026-08-30T14:00:55Z
- Timestamp Local: 2026-08-30 23:00:55 JST
- Module/Scope: corrected afterSRC permanent-support visual and artifact QA
- Command(s): `uv run --with pytest --with pyyaml pytest -q compactInVacuum/tests/test_platform_config.py compactInVacuum/tests/test_geometry.py`; `./compactInVacuum/run_freecad_tests.sh`; headless support-group mesh export/render; FreeCAD canonical STEP reopen; report/geometry-metrics audit.
- Key Parameters/Overrides: stationary supports rendered blue, ICF closure translucent red; UP pedestal bounds `x=[-220,-145], y=[160,200], z=[125.191,175.191] mm`.
- Validation Result: pure-Python `41/41` pass; all FreeCAD runtime groups pass; canonical report `47` pass / `10` warning / `0` fail; STEP reopens valid with `214` solids. All four holder-to-support and support-to-wall gaps are zero; support/pins/ground lift-corridor overlaps are zero.
- Artifacts/State: corrected standard views and comparison PNG regenerated; canonical state remains pass; no unrelated dirty worktree changes modified.
- Next Action: supplier/fabricator review of pedestal ribbing/fasteners and completion of the staged six-DOF extraction proof.

- Timestamp UTC: 2026-08-30T13:58:09Z
- Timestamp Local: 2026-08-30 22:58:09 JST
- Module/Scope: canonical corrected CompactInVacuum-afterSRC ICF305 fixed-support full export
- Command(s): `./compactInVacuum/run_compactOne_afterSRC.sh --pipeline-index codex_targets.yaml --force-rebuild`
- Key Parameters/Overrides: same corrected canonical configuration as the preceding validate-only run; removable closure carries no detector support/datum/ground ownership.
- Validation Result: prototype non-strict pass (`47` pass, `10` warnings, `0` fail). Load paths, permanent-wall contacts, ground bonds, lift-corridor clearance, LOS, target sweep, cable routing, and initial mount release pass; complete six-DOF extraction remains unresolved.
- Artifacts/State: canonical FCStd `1421433` bytes (`sha256=b0e09666...`), STEP `3151449` bytes (`sha256=84eadb4b...`, `55419` transfer entities), report/manifest/metrics regenerated under `artifacts/afterSRC/`; state pass.
- Next Action: render and inspect corrected support-focused views before handoff.

- Timestamp UTC: 2026-08-30T13:53:51Z
- Timestamp Local: 2026-08-30 22:53:51 JST
- Module/Scope: canonical corrected CompactInVacuum-afterSRC ICF305 fixed-support validate-only
- Command(s): `./compactInVacuum/run_compactOne_afterSRC.sh --pipeline-index codex_targets.yaml --validate-only --force-rebuild`
- Key Parameters/Overrides: canonical ICF305 with independent stationary wall supports, UP `-X` pedestal, holder-side dock, stationary locating pins, nonzero OFHC bonds, inward cable detours, and `12 mm` mount release.
- Validation Result: prototype non-strict pass (`47` pass, `10` warnings, `0` fail). All new structural/load-ownership checks and initial pin release pass; complete reorientation/top-lift remains an explicit strict-only warning.
- Artifacts/State: canonical validation report/manifest refreshed; `compactOne_afterSRC.state.json` pass.
- Next Action: perform the canonical full FCStd/STEP rebuild.

- Timestamp UTC: 2026-08-30T13:49:48Z
- Timestamp Local: 2026-08-30 22:49:48 JST
- Module/Scope: corrected CompactInVacuum-afterSRC ICF356 fixed-support comparison full export
- Command(s): `./compactInVacuum/run_compactOne_afterSRC_access_icf356.sh --pipeline-index codex_targets.yaml --force-rebuild`
- Key Parameters/Overrides: same stationary-pad support and nonzero ground-bond topology as corrected ICF305; ICF356 chamber remains `480 mm` long.
- Validation Result: prototype non-strict pass (`47` pass, `10` warnings, `0` fail); all structural/support/access ownership checks pass and detached-holder passage margin is `+74.561 mm`.
- Artifacts/State: corrected FCStd `1421852` bytes and STEP `3144289` bytes (`55263` transfer entities) exported under `artifacts/access_port_study/icf356/`; state pass.
- Next Action: validate and rebuild the canonical ICF305 artifact last.

- Timestamp UTC: 2026-08-30T13:45:42Z
- Timestamp Local: 2026-08-30 22:45:42 JST
- Module/Scope: corrected CompactInVacuum-afterSRC ICF305 fixed-support study full export
- Command(s): `./compactInVacuum/run_compactOne_afterSRC_access_icf305.sh --pipeline-index codex_targets.yaml --force-rebuild`
- Key Parameters/Overrides: removable UP holder ends at the inner dock near `x=-145 mm, y=180 mm`; stationary 75 mm `-X` wall pedestal remains with the chamber; LEFT/RIGHT/DOWN receive stationary 16 mm wall pads; all signal routes detour inward around the fixed supports.
- Validation Result: prototype non-strict pass (`47` pass, `10` warnings, `0` fail). Holder-to-pad, pad-to-real-wall, nonzero PE bond, access load ownership, cable clearance, `12 mm` inward release, and ICF305 passage (`+23.761 mm`) pass; continuous reorientation/top-lift remains unresolved.
- Artifacts/State: corrected FCStd `1421408` bytes and STEP `3151449` bytes (`55419` transfer entities) exported under `artifacts/access_port_study/icf305/`; state pass.
- Next Action: rebuild the corrected ICF356 comparison.

- Timestamp UTC: 2026-08-30T13:41:25Z
- Timestamp Local: 2026-08-30 22:41:25 JST
- Module/Scope: corrected CompactInVacuum-afterSRC ICF253 fixed-support comparison full export
- Command(s): `./compactInVacuum/run_compactOne_afterSRC_access_icf253.sh --pipeline-index codex_targets.yaml --force-rebuild`
- Key Parameters/Overrides: stationary wall supports added for all sectors; UP removable holder docks at `x=-145 mm, y=180 mm` to a stationary `-X` pedestal; nonzero OFHC ground bonds; `12 mm` inward pin-release stage.
- Validation Result: prototype non-strict pass (`46` pass, `11` warnings, `0` fail). Structural holder-to-support, support-to-wall, ground-to-wall, and load-free access checks pass; ICF253 remains rejected by the `-28.739 mm` flat-lift passage warning and also lacks the required supported-holder edge-on allowance.
- Artifacts/State: corrected FCStd `1419617` bytes and STEP `3122121` bytes (`54795` transfer entities) exported under `artifacts/access_port_study/icf253/`; state pass.
- Next Action: rebuild the corrected ICF305 study artifact.

- Timestamp UTC: 2026-08-30T09:10:32Z
- Timestamp Local: 2026-08-30 18:10:32 JST
- Module/Scope: CompactInVacuum-afterSRC access-port regression and visual QA
- Command(s): `uv run --with pytest --with pyyaml pytest -q compactInVacuum/tests/test_platform_config.py compactInVacuum/tests/test_geometry.py`; `./compactInVacuum/run_freecad_tests.sh`; headless FCStd mesh export and four-view rendering through `export_access_port_review_meshes.py` / `render_access_port_review_meshes.py`; FreeCAD STEP reopen audit.
- Key Parameters/Overrides: ICF253/305/356 candidate comparison; physical/purchased roles only in review images; keepouts remain in FCStd/JSON.
- Validation Result: pure-Python `41/41` pass; all FreeCAD runtime groups pass; four STEP files reopen as valid non-null compounds with `209` solids each; visual review confirms ICF305 is the balanced active layout and ICF356 has the tightest service margin.
- Artifacts/State: twelve standard-view PNGs plus `artifacts/access_port_study/afterSRC_access_port_comparison.png`; canonical ICF305 state remains pass and was not overwritten by rendering.
- Next Action: supplier review of the ICF305 fixed/blank flange drawings, weld-neck detail, structural analysis, and a continuous sector extraction demonstration.

- Timestamp UTC: 2026-08-30T08:57:37Z
- Timestamp Local: 2026-08-30 17:57:37 JST
- Module/Scope: canonical CompactInVacuum-afterSRC ICF305 maintenance-access full export
- Command(s): `./compactInVacuum/run_compactOne_afterSRC.sh --pipeline-index codex_targets.yaml --force-rebuild`
- Key Parameters/Overrides: active ICF305 all-metal access port; `251.0 mm` clear bore; OFHC copper gasket; `420 mm` chamber; helium leak acceptance target `<=1.0e-10 Pa m^3/s`; no elastomer seal.
- Validation Result: prototype non-strict pass (`41` pass, `10` warnings, `0` fail). Access flange fit, `14.056 mm` service clearance, `23.761 mm` conservative passage margin, nominal metal-seal topology, closed vacuum control volume, LOS, target sweep, and services pass; strict engineering release remains open on evidence gates.
- Artifacts/State: canonical FCStd `1399170` bytes (`sha256=ab9e1bf7...`), STEP `3132420` bytes (`sha256=b325736c...`, `55046` transfer entities), geometry metrics/report/manifest regenerated under `artifacts/afterSRC/`; `compactOne_afterSRC.state.json` pass.
- Next Action: render and visually inspect ICF253/305/356 standard comparison views, then audit final diffs and states.

- Timestamp UTC: 2026-08-30T08:54:22Z
- Timestamp Local: 2026-08-30 17:54:22 JST
- Module/Scope: canonical CompactInVacuum-afterSRC ICF305 maintenance-access validate-only
- Command(s): `./compactInVacuum/run_compactOne_afterSRC.sh --pipeline-index codex_targets.yaml --validate-only --force-rebuild`
- Key Parameters/Overrides: canonical profile now selects the all-metal top ICF305 port, OFHC copper gasket, `420 mm` chamber, and relocated top signal services.
- Validation Result: prototype non-strict pass (`41` pass, `10` warnings, `0` fail); all access integration geometry checks pass, while purchased drawings, structural release, materials, site envelope, and continuous extraction remain evidence warnings.
- Artifacts/State: `compactOne_afterSRC.state.json` is pass; canonical validation report and channel manifest refreshed under `artifacts/afterSRC/`.
- Next Action: run the canonical full build/export and retain ICF305 as the final active state.

- Timestamp UTC: 2026-08-30T08:51:26Z
- Timestamp Local: 2026-08-30 17:51:26 JST
- Module/Scope: CompactInVacuum-afterSRC ICF356 enlarged maintenance-access comparison full export
- Command(s): `./compactInVacuum/run_compactOne_afterSRC_access_icf356.sh --pipeline-index codex_targets.yaml --force-rebuild`
- Key Parameters/Overrides: same ICF356 all-metal enlarged-envelope comparison as the preceding validate-only run.
- Validation Result: prototype non-strict pass (`41` pass, `10` warnings, `0` fail); passage is roomy but service clearance is only `11.109 mm` and chamber length is `480 mm`.
- Artifacts/State: FCStd `1397226` bytes (`sha256=ca49df4a...`), STEP `3125258` bytes (`sha256=b3eb8322...`, `54890` transfer entities), geometry metrics/report/manifest exported under `artifacts/access_port_study/icf356/`; state pass.
- Next Action: rebuild the canonical afterSRC artifact with ICF305 selected.

- Timestamp UTC: 2026-08-30T08:48:15Z
- Timestamp Local: 2026-08-30 17:48:15 JST
- Module/Scope: CompactInVacuum-afterSRC ICF356 enlarged maintenance-access comparison validate-only
- Command(s): `./compactInVacuum/run_compactOne_afterSRC_access_icf356.sh --pipeline-index codex_targets.yaml --validate-only --force-rebuild`
- Key Parameters/Overrides: top `ICF356`, `301.8 mm` clear bore, OFHC copper gasket, `480 mm` chamber length, access center `(x,z)=(0,230) mm`, common relocated signal-port layout.
- Validation Result: prototype non-strict pass (`41` pass, `10` warnings, `0` fail); conservative flat-lift passage margin `+74.561 mm`, minimum service-port clearance `11.109 mm`; complete extraction remains unresolved.
- Artifacts/State: `compactOne_afterSRC_access_icf356.state.json` is pass; report and manifest refreshed under `artifacts/access_port_study/icf356/`.
- Next Action: run the ICF356 comparison full build/export.

- Timestamp UTC: 2026-08-30T08:45:20Z
- Timestamp Local: 2026-08-30 17:45:20 JST
- Module/Scope: CompactInVacuum-afterSRC ICF305 recommended maintenance-access full export
- Command(s): `./compactInVacuum/run_compactOne_afterSRC_access_icf305.sh --pipeline-index codex_targets.yaml --force-rebuild`
- Key Parameters/Overrides: same selected ICF305 all-metal access configuration as the preceding validate-only run.
- Validation Result: prototype non-strict pass (`41` pass, `10` warnings, `0` fail); access fit, service clearance, conservative passage, nominal metal-seal topology, and vacuum-control-volume closure pass.
- Artifacts/State: FCStd `1399025` bytes (`sha256=63ade0b8...`), STEP `3132420` bytes (`sha256=ec3110d0...`, `55046` transfer entities), geometry metrics/report/manifest exported under `artifacts/access_port_study/icf305/`; state pass.
- Next Action: validate the enlarged ICF356 comparison.

- Timestamp UTC: 2026-08-30T08:42:02Z
- Timestamp Local: 2026-08-30 17:42:02 JST
- Module/Scope: CompactInVacuum-afterSRC ICF305 recommended maintenance-access validate-only
- Command(s): `./compactInVacuum/run_compactOne_afterSRC_access_icf305.sh --pipeline-index codex_targets.yaml --validate-only --force-rebuild`
- Key Parameters/Overrides: top `ICF305`, `251.0 mm` clear bore, OFHC copper gasket, `420 mm` chamber length with upstream face retained, access center `(x,z)=(0,190) mm`, relocated signal ports.
- Validation Result: prototype non-strict pass (`41` pass, `10` warnings, `0` fail); conservative flat-lift passage margin `+23.761 mm`, minimum service-port clearance `14.056 mm`; continuous extraction remains unresolved.
- Artifacts/State: `compactOne_afterSRC_access_icf305.state.json` is pass; report and manifest refreshed under `artifacts/access_port_study/icf305/`.
- Next Action: run the ICF305 study full build/export.

- Timestamp UTC: 2026-08-30T08:39:05Z
- Timestamp Local: 2026-08-30 17:39:05 JST
- Module/Scope: CompactInVacuum-afterSRC ICF253 maintenance-access comparison full export
- Command(s): `./compactInVacuum/run_compactOne_afterSRC_access_icf253.sh --pipeline-index codex_targets.yaml --force-rebuild`
- Key Parameters/Overrides: same ICF253 all-metal comparison configuration as the preceding validate-only run.
- Validation Result: prototype non-strict pass (`40` pass, `11` warnings, `0` fail); ICF253 remains constrained by the `-28.739 mm` flat-lift screen.
- Artifacts/State: FCStd `1393591` bytes (`sha256=24cc4480...`), STEP `3103088` bytes (`sha256=67f09efa...`, `54422` transfer entities), geometry metrics/report/manifest exported under `artifacts/access_port_study/icf253/`; state pass.
- Next Action: validate the recommended ICF305 study profile.

- Timestamp UTC: 2026-08-30T08:35:22Z
- Timestamp Local: 2026-08-30 17:35:22 JST
- Module/Scope: CompactInVacuum-afterSRC ICF253 maintenance-access comparison validate-only
- Command(s): `./compactInVacuum/run_compactOne_afterSRC_access_icf253.sh --pipeline-index codex_targets.yaml --validate-only --force-rebuild`
- Key Parameters/Overrides: top `ICF253`, `198.5 mm` clear bore, OFHC copper gasket, `360 mm` chamber length, relocated signal ports, elastomer seal prohibited, helium leak requirement `<=1.0e-10 Pa m^3/s`.
- Validation Result: prototype non-strict pass (`40` pass, `11` warnings, `0` fail); flat-lift passage warning with `-28.739 mm` margin, while continuous reorientation/lift remains unresolved.
- Artifacts/State: `compactOne_afterSRC_access_icf253.state.json` is pass; validation report and channel manifest refreshed under `artifacts/access_port_study/icf253/`.
- Next Action: run the stateful full build/export for the ICF253 comparison artifact.

- Timestamp UTC: 2026-04-12T11:45:40Z
- Timestamp Local: 2026-04-12 20:45:40 JST
- Module/Scope: compactInVacuum (full stateful build/export)
- Command(s): `./compactInVacuum/run_compactInVacuum.sh --pipeline-index codex_targets.yaml`
- Key Parameters/Overrides: default target `compactInVacuum/target.yaml`; strict validation enabled; no overrides
- Validation Result: pass
- Artifacts/State: `state.json.run.status=pass`, `validation.status=pass`, `compactInVacuum.FCStd`, `compactInVacuum.step`, and `compactInVacuum.validation_report.json` regenerated
- Next Action: provide artifact paths to the user and collect follow-up geometry changes if needed.
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

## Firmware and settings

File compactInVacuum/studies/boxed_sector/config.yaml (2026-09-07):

extends: ../../config/reference_afterSRC_top_boxed.yaml
doc_name: BoxedSectorStudy
deployment:
  boxed_support:
  support_frame:

boxed_sector_study:
  sector: right
  cheek_inner_half_width_mm: 18.0
  cheek_thickness_mm: 3.0
  carrier_r_min_mm: 23.0
  carrier_r_max_mm: 182.0
  carrier_z_min_mm: 110.0
  carrier_z_max_mm: 205.0
  cheek_corner_radius_mm: 4.0
  cheek_windows_mm: [[62.0, 141.0, 95.0, 53.0, 6.0], [72.0, 117.0, 73.0, 15.0, 4.0]]
  front_brace_mm: [90.0, 110.0, 14.0, 6.0]
  rear_bridge_depth_mm: 6.0
  rear_bridge_attachment_r_mm: 157.0
  nest_boss_tangent_mm: 15.3
  nest_boss_radius_mm: 2.7
  clamp_width_local_x_mm: 10.0
  side_attachment_local_x_mm: 8.0
  side_bolt_radius_mm: 1.0
  side_bolt_head_radius_mm: 2.0
  side_bolt_head_depth_mm: 1.2
  fastener_clearance_mm: 0.25
  ring_inner_radius_mm: 185.0
  ring_outer_radius_mm: 205.0
  ring_front_z_mm: 135.0
  ring_depth_mm: 10.0
  wall_foot_width_mm: 24.0
  dock_plane_r_mm: 182.0
  dock_depth_mm: 6.0
  dock_z_min_mm: 143.0
  dock_z_max_mm: 166.0
  pin_center_z_mm: 150.0
  pin_tangent_spacing_mm: 18.0
  pin_diameter_mm: 3.0
  pin_projection_mm: 8.0
  pin_bore_diameter_mm: 3.5
  slot_length_mm: 6.0
  draw_screw_head_mm: [177.0, 15.0, 160.0]
  draw_screw_access_direction: [-72.0, 220.0, 40.0]
  draw_screw_shaft_radius_mm: 1.5
  draw_screw_shaft_length_mm: 24.0
  draw_screw_head_radius_mm: 2.8
  draw_screw_head_depth_mm: 3.0
  draw_screw_withdrawal_mm: 36.0
  screwdriver_radius_mm: 2.5
  screwdriver_length_mm: 360.0
  grip_center_mm: [70.0, 0.0, 190.0]
  grip_pin_radius_mm: 3.0
  grip_pin_length_mm: 8.0
  grip_head_radius_mm: 6.0
  grip_bearing_clearance_mm: 0.15
  grip_head_depth_mm: 6.0
  grip_rod_radius_mm: 3.0
  grip_rod_length_mm: 350.0
  grip_jaw_open_offset_mm: [14.0, -12.0, 0.0]
  grip_fork_half_width_mm: 5.0
  grip_fork_plate_depth_mm: 2.0
  grip_fork_anchor_r_mm: 55.0
  grip_relief_z_half_span_mm: 6.0
  cable_radius_mm: 0.5
  cable_bend_radius_mm: 5.0
  connector_radius_mm: 3.0
  connector_body_length_mm: 6.0
  connector_r_mm: 170.0
  connector_z_mm: [168.0, 200.0, 179.0]
  cable_turn_r_mm: [120.0, 80.0, 145.0]
  cable_lane_y_mm: [10.0, 10.0, 16.0]
  cable_lane_merge_r_mm: [130.0, 120.0, 154.0]
  large_angle_cable_turn_z_mm: 142.0
  connector_plug_length_mm: 12.0
  connector_plug_collar_radius_mm: 4.0
  connector_plug_collar_depth_mm: 2.0
  connector_withdrawal_mm: 100.0
  connector_parking_x_mm: 210.0
  connector_parking_y_mm: 80.0
  parking_clip_outer_radius_mm: 5.0
  parking_clip_bore_radius_mm: 3.2
  parking_clip_y_mm: [84.0, 90.0]
  parking_backplate_mm: [214.5, 70.0, 96.0, 153.0, 207.0]
  ground_parking_pegs_mm: [199.0, 203.0, 114.2, 152.0, 158.0]
  ground_parking_peg_radius_mm: 2.0
  ground_parking_backplate_mm: [197.0, 110.0, 116.2, 150.0, 152.0]
  ground_parking_translation_mm: [18.0, 90.0, 0.0]
  ground_bond_radius_mm: 0.8
  radial_release_mm: 14.0
  downstream_translation_mm: 100.0
  rotation_deg: 90.0
  lift_mm: 360.0
  neighbor_r_min_mm: 22.5
  neighbor_r_max_mm: 182.0
  neighbor_half_width_mm: 21.0
  neighbor_z_min_mm: 110.0
  neighbor_z_max_mm: 205.0
  continuous_clearance_mm: 0.10
  interval_min_fraction: 0.00001
  interval_max_depth: 20
  collision_volume_tolerance_mm3: 0.000001

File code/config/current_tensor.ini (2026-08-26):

[meta]
scenario_name = current_tensor

[beam]
deuteron_mass_mev = 1875.612
proton_mass_mev = 938.0
kinetic_energy_mev = 380.0

[target]
areal_density_g_per_m2 = 10000.0
molar_mass_g_per_mol = 14.0
avogadro = 6.02214076e23

[run]
beam_current_amp = 1.6e-12
electron_charge_c = 1.602176634e-19
duration_s = 10800.0
duration_s_list = 600.0, 3600.0, 10800.0
single_arm_sector_multiplier = 4.0
lrud_sector_multiplier = 2.0
coincidence_sector_multiplier = 4.0
integration_steps = 400

[scan]
polarization_min = -2.0
polarization_max = 1.0
polarization_steps = 30

[coverage]
theta_bins = 720
phi_bins = 720

[data]
observables_dir = ../data/observables
cross_section_file = DSigamaOverDOmega.txt
tensor_file = CompletSetOFT/T.txt
energy_range_file = ../data/energy_lise/H_c8h8_range.txt

[geometry_contract]
source_config = ../../compactInVacuum/config/common_detector.yaml
radius_reference = active_center
active_face_shape = circle
acceptance_model = legacy_top_hat_theta_with_finite_phi_harmonics

[detector_model]
response_status = planned_geometry_provisional_response
active_medium = plastic_scintillator
photosensor = sipm
active_diameter_mm = 20.0
active_length_mm = 5.5

[custom_layout]
; [EN] The response uses a 20x20 mm tangent-plane approximation while retaining finite azimuthal harmonics / [CN] 响应计算采用 20x20 mm 切平面近似，并保留有限方位角谐波积分
proton_theta_lab_deg = 53.4, 11.2
proton_distance_mm = 205.0, 190.0
proton_width_theta_mm = 20.0, 20.0
proton_width_phi_mm = 20.0, 20.0
deuteron_theta_lab_deg = 20.9
deuteron_distance_mm = 140.0
deuteron_width_theta_mm = 20.0
deuteron_width_phi_mm = 20.0

[sekiguchi_layout]
deuteron_theta_lab_deg = 20.1, 22.7, 25.6, 29.3
deuteron_distance_mm = 560.0
deuteron_width_theta_mm = 24.0, 24.0, 24.0, 50.0
deuteron_width_phi_mm = 24.0, 24.0, 24.0, 50.0
proton_theta_lab_deg = 21.3, 26.1, 30.9, 35.8, 40.8, 45.0, 50.8, 55.9
proton_distance_mm = 560.0
proton_width_theta_mm = 20.0
proton_width_phi_mm = 20.0

[energy_loss]
enabled = false

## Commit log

2026-02-20 initial commit3
    [Ladder_base.dwg, Ladder_base.stp, Target_mechanism_Jan_30_2018.stp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]
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2026-03-07 infrontofSamuraiMag: freeze legacy-center preview baseline for iterative tuning
    - add locked preview profile and point target build config to it
    - keep preview gating: no plate cuts, overlap checks skipped, strict=false
    - preserve center-aligned plate offsets for next-step parameter tuning
2026-03-12 add mle. and doc polarimeter_stastic
    [duration_runs.csv, inference_scan.csv, likelihood_scan.csv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]
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2026-03-15 calculate the layout, coincidence to veto dc scattering
    [PDP-∅40X10-F 25.7.7.xlsx]
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2026-04-08 ifsm: rebuild detector fixture as rigid side-clamp support carrier
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2026-04-17 docs: add detector clamp weldment redesign spec (Sub-2)
    Scope: first sub-project in manufacturability decomposition.
    Preserves BLP_v1 topology; rewrites detector fixture via PartDesign
    API to emit 3 clean Body solids (weldment / upper half-clamp / base
    plate) + real fastener solids, with per-fixture interpenetration gate.
2026-04-17 docs: add Sub-2 clamp/weldment redesign implementation plan
    15-task plan sequenced as Phase 0 headless PartDesign spike (gating);
    config + fastener primitives; three Bodies (Weldment_LoadBearing,
    UpperClamp_Detachable, BasePlate_Bolted); fastener placement;
    detector_fixture_no_interpenetration validator; afterSRC + ifsm
    regression; visual review and DoD sign-off.
2026-04-17 fix phase 0 spike hole API and reorder for coverage
2026-04-18 tighten phase 0 spike fillet and hole criteria with volume check
2026-04-18 tighten phase 0 hole criterion to compare against pre-hole volume
2026-04-18 Phase 0 PartDesign feasibility report and worklog entries
    [spike_body.step]
2026-04-18 clarify phase 0 report and untrack spike step artifact
    [spike_body.step]
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2026-04-19 add build_weldment_load_bearing as Part::Feature (Path B)
    Wraps build_detector_fixture's fused support_carrier shape into a named
    Part::Feature. Phase 0 showed PartDesign::Body multi-pad assemblies at
    disparate world positions yield Null shapes and broken Fillet.Base edge
    links in headless freecadcmd; Path B sidesteps those by publishing the
    already-fused Part shape as the weldment. BLP_v1 topology is preserved
    via the shared primitive chain.
    Tests: single-solid + volume>0 for first placement, and all 12 BLP_v1
    placements build in one document.
2026-04-19 add build_upper_clamp_detachable as Part::Feature (Path B)
    Wraps build_detector_fixture's clamp_half_a (upper half of the split clamp
    ring) into a named Part::Feature. Uses the same Path B pattern adopted for
    Weldment_LoadBearing to avoid the multi-pad PartDesign::Body carve-outs the
    Phase 0 spike surfaced.
    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
2026-04-19 add build_base_plate_bolted as Part::Feature (Path B)
    Wraps build_detector_fixture's mount_base (the plate-mounted base plate
    independent of the load-bearing weldment) into a named Part::Feature.
    Completes the Sub-2 triad (weldment + upper clamp + base plate) on the
    uniform Path B strategy.
    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
2026-04-20 Fix detector fixture interpenetration: disjoint clamp halves, bolt clearance cuts, fastener reseating
    - Make clamp_half_a / clamp_half_b masks strictly disjoint at the split plane (each now spans 2*OD on its own side); clip ears by the matching mask before fuse so the intentional ear-to-ring bite stays on its own half.
    - Cut mount_base out of support_carrier for bolt clearance, then cut support_carrier out of mount_base_plate so the two published bodies share no volume while the weldment remains continuous through clearance slots.
    - Reseat clamp bolts on the outer face of the -split_axis ear with shank_length = clamp_bolt_span so the head/shank sits entirely inside the ear + gap + ear sandwi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
2026-04-20 Add detector_fixture_no_interpenetration validator and Task 11 tests
    - New validator detector_fixture_no_interpenetration: body-body pairs use strict 1e-6 mm^3 tolerance; bolt-vs-body pairs use 1e-3 mm^3 whitelist for through-hole OCC artefacts; non-bolt fasteners (nuts, washers) stay strict.
    - Wire the check into _validate_detector for all 12 placements; honours geometry.clearance.skip_overlap_checks.
    - Doc-less adapter _build_detector_fixture_for_interpenetration_check mirrors build_detector_fixture's fastener placement so strict validation agrees with the live geometry.
    - tests/test_fixture_interpenetration.py covers clean-fixture pass, weldment-vs-base-plate fail, and bolt-through-hole w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
2026-05-10 v1.33 clamp: build_lower_half_clamp body with cradle + csk holes
    Add _half_plate_with_cradle shared core and build_lower_half_clamp wrapper.
    New primitives in primitives.py: pocket_cradle_through_axis (shallow circular-
    arc-segment trough via PartDesign Pocket, Midplane along detector axis),
    add_csk_hole (two-pocket countersunk clearance hole), M2.5 entry in
    _CLEARANCE_D, _ensure_partdesign() auto-loader for PartDesign::Body in
    headless environments. Chamfer predicate now requires both vertices to be on
    3 bbox face planes (plate corner) to exclude interior cradle chord edges.
    6 tests pass: single solid, 70×60×10 bbox, pocket floor at z=-5, R=25.1
    cylindrical face, 4 M4 holes (combined mode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
2026-06-24 compactInVacuum: scaffold compact in-vacuum polarimeter module
    New stateful module (civ package): square-section vacuum chamber at
    140/190/205 mm radii with BLP-v1 angles (11.2/20.9/53.4 deg), 3x4=12
    plastic scintillator placeholders on internal frame arms, and modular
    front/rear ICF114 welded pipe-stub flange interfaces (JIS-swapplable).
    - src/civ: assembly/components/config/layout/validation/export/stateflow/cli
    - config: default_compactInVacuum.yaml + example_jis_vf100.yaml profile
    - tests/test_geometry.py, target.yaml, run_compactInVacuum.sh, worklog
    - register module in codex_targets.yaml
    [default_compactInVacuum.yaml]
2026-06-24 ifsm/export: add IFSM_SKIP_FCSTD_ROUNDTRIP bypass for 300+ VP assemblies
    With fasteners drawn as Part::Feature-wrapped solids the detector-clamp
    weldment redesign raised viewprovider-bearing objects from 132 to ~330.
    Offscreen Qt deadlocks during GUI init (futex_wait_queue across 64/65
    threads, frozen CPU; FreeCAD #22870 class of bug).
    Setting IFSM_SKIP_FCSTD_ROUNDTRIP=1 bypasses ensure_fcstd_gui_session,
    _prepare_fcstd_gui_state, and the App.openDocument reopen check. The
    FCStd is saved without GuiDocument.xml (FreeCAD #23376 behavior) but
    opens fine in the GUI with default visibility; _verify_fcstd_archive
    (zip-structure check) replaces the reopen roundtrip so large assemblies
    still expor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
2026-06-24 ifsm/validation: emit clamp parts_manifest in validation report json
    build_clamp_parts_manifest(cfg, placements) produces a per-placement
    7-line manifest (3 make: weldment / upper-clamp / base-plate; 4 buy:
    clamp bolt, plate-side bolt, washer, weldment-side nut) with thread
    sizes routed through _bolt_diameter_to_thread (6 mm -> M6, 9 mm
    clearance -> M8). report_to_dict / write_report_json thread the
    manifest through, and the CLI builds it from the validated placements
    so strict-validation reports now carry an inventory-level BOM.
2026-06-24 sub2: add Task 14 review notes + Task 13/14/15 worklog entries
    - reports/sub2_before_after/review_notes.md: static Document.xml
    inventory after the weldment redesign (330 afterSRC / 324 ifsm
    Part::Feature objects; 12x W/U/B triplets, 192 fasteners per module),
    checklist of spec-confirmed items, and human-GUI capture instructions
    for the deferred before/after screenshots.
    - append Task 13 (strict-validate + force-rebuild), Task 14 (review),
    and Task 15 (parts_manifest) entries to the root, ifsm, and afterSRC
    worklogs.
2026-07-26 add commpact version tex. sipm and scitillator information
    [energy_deposition.csv, sipm_curve.csv, sipm_saturation.csv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]
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2026-07-27 docs: correct CompactInVacuum two-instrument baseline
    [common_detector.yaml]
2026-07-29 redesign: rebuild compact detector head and sector holder
    [common_detector.yaml, default_compactInVacuum.yaml]
2026-07-29 fix: select square chamber for compact afterSRC
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2026-08-23 analysis: quantify tensor transport and polarimeter response
    [beam_steering_bias.csv, bend_table.csv]
2026-08-26 docs: publish tensor identifiability study
    [fisher_profiled.csv, nominal_pyy_fisher_profiled.csv, nominal_pyy_jacobian.csv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]
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2026-09-01 docs: refresh canonical report data
    [energy_deposition.csv, sipm_saturation.csv, thickness_scan.csv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]
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2026-09-06 cad: support review rendering of canonical compact artifacts
    Allow retained review tools to export a selected FCStd and render assembly or support-focused standard views. Verified both Python modules compile and the renderer CLI loads in an isolated scientific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
2026-09-06 cad: unify compact supports on a rear open frame
    Replace the afterSRC UP side arm and independent wall mounts with a common
    stationary C-frame, four equal plane-pin-slot docks and separate M4 clamp
    envelopes. Both compact deployments use ICF305 top access; preSAMURAI moves
    to a 420 mm chamber while retaining its upstream face and detector geometry.
    Reserve a forepart internal staging corridor ahead of the fixed pins and
    verify a 20 mm upstream release, structural and grounding continuity,
    acceptance clearance, and cable routing through the frame aperture.
    Complete independent sector reorientation/lift remains unproven; the
    existing strict supplier/site/material/structural evidence gates rem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
    [common_open_frame.yaml]
2026-09-06 cad: render detailed detector and handling-tool review views
    Add optional neighbor reservation overlays and distinct carrier, detector and tool groups. Sort triangles globally so a carrier collection cannot incorrectly hide all detector faces. Verified STL ext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
2026-09-06 cad: build a boxed sector with certified modeled extraction
    Register an isolated RIGHT-sector study with two carrier cheeks, three
    detector nests, a plane-pin-slot dock, an accessible draw screw, curved
    passive coax, a capture interface and a near-detector annular support.
    Model wall-mounted plug parking seats and ground-jumper hangers.
    Certify all modeled preparation/handling motion using exact mating sweeps
    and distance/displacement interval bounds. Independently verified empty
    regions accelerate distance bounds without removing obstacles. Reject
    collisions, unproved intervals and undeclared mating exclusions.
    The scope is one detailed RIGHT sector against three conservative neighbor
    res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
    [config.yaml]
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2026-09-07 cad: complete four boxed sectors in both compact deployments
    Replace both canonical rear C-frame assemblies with four detailed three-head carriers, a permanent annular support, rear handling journals, axial retaining bridges and twelve installed/parked signal looms. Preserve site-specific chamber interfaces and all frozen detector geometry.
    Validate the UP/RIGHT/LEFT/DOWN sequence with 51 modeled motion phases, exact mating certificates and complete angular bounds. Both prototype reports pass 111 checks with 7 evidence warnings; full maintenance-process and fabrication qualification remain explicit open gates. Export complete FCStd/STEP assemblies, four standalone sectors and seventeen main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
    [common_boxed.yaml, common_open_frame.yaml]
2026-09-07 docs: document RIKEN polarized beam production and transport
    Trace source preparation, single-turn extraction, calibration and target spin transport to original publications, including Sekiguchi team contributions and proposed experiment handover. Include elev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
    Validated: make -C docs/polarization_production_transport; make -C docs/polarization_production_transport verify; inspected all 16 rendered pages and recomputed ideal-dipole examples. Source PDFs and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
2026-09-07 docs: add concise English polarized-beam reference
    Condense the Chinese report into seven pages with direct affirmative prose, seven source screenshots, English references and exact PDF locators. Preserve the production, acceleration, calibration, tr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
    Validated with make -C docs/polarization_production_transport en and verify; all seven final pages visually reviewed.
2026-09-07 docs: describe polarization support during beam operation
    Replace the publication and deliverable overview with PIS mode tuning, Wien-axis setting, joint single-turn diagnostics, polarimeter operation, mode cycling and recovery checks. Cite the official Cyclotron Team remit and identify the run-specific role assessment.
    Validated: make -C docs/polarization_production_transport en; make -C docs/polarization_production_transport verify. Reviewed revised PDF pages 1, 6 and 7; document remains seven pages.
2026-09-07 docs: rewrite Chinese beam-time polarization roles
    Describe PIS/RF tuning, Wien-axis setup, joint single-turn diagnosis, polarimeter operation, mode monitoring and recovery checks in the Chinese edition. Replace the publication overview and handover table; update the abstract and source index with the Cyclotron Team remit.
    Validated: make -C docs/polarization_production_transport zh; make -C docs/polarization_production_transport verify. Reviewed revised PDF pages 1, 13, 14 and 16; checked ten cited crops and reference resolution.
2026-09-07 cad: move compact access and signals to opposite side walls
    Keep rotary target hardware on top, put the signal interfaces on the left and ICF305 maintenance access on the right for both compact instruments. Replace the inaccessible annular weldment with four removable local supports, welded wall pads and blind mounting-fastener interfaces.
    Certify initial support insertion through the actual side opening and the RIGHT/DOWN/UP/LEFT module service sequence. Export both full instruments, support assemblies, installation poses and side-extraction poses. Preserve top-boxed configurations for existing studies and regressions.
    Validation: both non-strict reports pass 136 checks with 7 explicit en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
    [common_side_access.yaml, config.yaml, reference_afterSRC_top_boxed.yaml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]
2026-09-07 docs: add RIKEN RF modes and polarimetry references
    Add Okamura 1995 RF-mode table, Sekiguchi 2002 energy-indexed analyzing powers, and Mardanpour 2007 two-station axis measurements to the Chinese and English notes. Pin source PDFs and reproduce the t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
    Validation: make all; make verify; git diff --check; rendered page review. The pre-existing untracked timeline was updated locally and is intentionally excluded from this commit.
2026-09-07 docs(afterSRC): explain the case for a T11 polarimeter
    Describe tuning, upstream/downstream diagnosis, and complementary density-matrix measurements. Distinguish the 27.513 degree axis rotation at 190 MeV/u from the 55.026 degree tensor harmonic.
    Validation: make -C docs/beamline_info/afterSRC/polarimeter_rationale; three-page PDF visually checked; existing BMT and polarimeter-response functions reproduce rotations and ranks 6/8 to 8/8, tenso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
2026-09-08 docs: group physics, analysis and paper topics
    Move complete topic directories with their assets; keep beamline locations and requirement baselines stable. Update source-manifest links, document references and plotting output paths. Preserve exis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
    Validation: eleven LaTeX documents compile after relocation; all eleven source-PDF hashes pass capture_sources.py --verify-only; dpol_plot_cross_sections builds and renders with anaroot-env; 656 pre-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
    [beam_steering_bias.csv, bend_table.csv, duration_runs.csv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]
2026-09-08 docs(bigrips): substantiate beam intensity claims with source screenshots
    Embed seven unretouched RIKEN source captures with dates, page locators, and source hashes. Attach claims to citations and distinguish F3 proposal guidance and ATT-specific FC logic from engineering 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
    Validation: compile_latex.py --compiler texlive --engine xelatex --output-directory /tmp/bigrips-evidence/build; pdftoppm visual review of all seven pages; warning-free LaTeX log; git diff --check. G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
2026-09-10 docs(presentation): focus on positive pure-tensor mode
    Comment out the pyy=-2 population, RF recipe, switching explanation, and historical measurement for later reuse. Present only the ideal (py,pyy)=(0,+1) mode and update the matching Chinese notes.
    Validation: make -C docs/presentations/pis-samurai-planning pdf; inspect changed slide and note renders. Both PDFs retain six pages beside their TeX sources, contain no deferred negative-mode discussion, and compile without overflow or missing-glyph warnings.
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2026-09-10 docs(physics): clarify bilingual deuteron spin-space notes
    Organize the derivation from spin-orbital coupling through the spatial density to tensor modes and coordinate sampling. Remove repeated corrective framing and state the sampling measure explicitly.
    Validation: make pdf; both XeLaTeX builds complete without warnings. Numbered equations match across languages; all PDF pages visually reviewed.
2026-09-11 docs(presentation): add 10s and 20s pyy confidence bands
    Use current_tensor.ini and the existing coincidence LR/UD conditional-binomial inference to plot nominal 68.3% and 95% profile-likelihood intervals from Asimov counts. Display true pyy from zero to one while retaining the physical fit domain. Add two slides, matching Chinese notes, and reproducible plot/build targets. PDFs remain beside the TeX sources.
    Assumptions: 190 MeV/u, 1.6e-12 A, provisional 1000 mg/cm2 CH2, nominal 20 mm heads with existing acceptance approximation, fixed analyzing powers and unit efficiency/live time. Validation: build dpolar in anaroot-env; ctest -R '^dpolar_tests$' passed. Check 101 truth points per durati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
2026-09-11 docs(presentation): compare reference and scaled-count precision
    Arrange six Asimov confidence-band plots as three pages with 10s and 60s side by side. Retain the reference and add counts x10 and x100 for hypothetical downstream ATT/slit transmission 1/10 and 1/100. Only count normalization changes; geometry, analyzing powers, and response assumptions remain fixed.
    Update Chinese notes, shared numerical tables, plot labels, and build dependencies. Validation: make -C docs/presentations/pis-samurai-planning pdf; verify LR/UD and total count multipliers, 101 truth points per case, profile-likelihood thresholds, interval nesting, nine-page PDFs, six embedded figures, and rendered text bounds.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
